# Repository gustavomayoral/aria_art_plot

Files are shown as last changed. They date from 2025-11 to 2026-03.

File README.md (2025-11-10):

# Aria Art Plotter





**Professional large-format CNC drawing machine for artists and creators**

This is the Aria Art Plotter, a pen plotter made for artist.

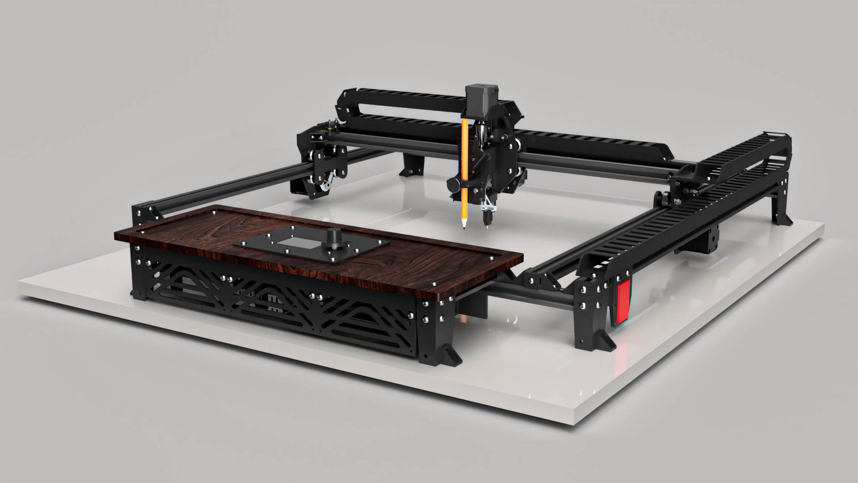
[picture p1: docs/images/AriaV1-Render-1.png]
Aria Art Plotter


---

## ✨ Key Features

- **Large Drawing Area**: 500mm × 500mm (20" × 20") usable area, expandable
- **Multi-Tool Support**: Pens, pencils, brushes, stamps, and more
- **Artist-Friendly**: Simplified interface designed for creators, not engineers
- **Whisper Quiet**: Silent TMC2209 stepper drivers
- **Smart Compensation**: Dual mesh system for beds and canvases
- **Remote Control**: WiFi/Ethernet connectivity with web interface
- **Open Source**: Complete build documentation, all files included

---

## 📋 What's Included in This Repository

This is a **complete open source package** to build your own Aria Art Plotter:

- **📘 170-Page Assembly Guide** - Complete safety instructions, BOM, visual IKEA-style assembly
- **🎥 15 Video Tutorials** - Step-by-step build process ([YouTube Channel](https://www.youtube.com/@aria_art_plot))
- **🔧 All Design Files**:
  - STL files for 3D printing
  - DXF files for CNC/laser cutting
  - 1 Arduino sketch
  - 3 Klipper configuration files with custom macros
  - 1 Python support file
- **📦 Complete Bill of Materials** - Every component with sources and alternatives

---

## 🎯 Who Is This For?

- **Artists** wanting to create large-format physical artwork from digital designs
- **Makers** interested in precision CNC systems and creative robotics
- **Educators** teaching about digital fabrication and art technology
- **Hobbyists** who enjoy building capable, professional-grade tools

---

## 🚀 Quick Start

### Prerequisites

- Basic mechanical assembly skills
- 3D printer access (for printed parts)
- Basic electronics knowledge (soldering, crimping)
- Budget: Cost of Materials. Check BOM on Amazon here: 

### Build Process Overview

1. **Review Documentation**: Read the [Assembly Guide](docs/AriaArtPlotterAssemblyManual_V1.pdf)
3. **Print Parts**: Download [STL files](hardware/stl/) and print components as per manual instruction
4. **Optional Cut Parts**: Process [DXF files](hardware/dxf/) for frame parts
5. **Assemble**: Follow video tutorials and assembly guide
6. **Install Firmware**: Configure [Klipper](firmware/klipper/) on the CB1
7. **Calibrate**: Run test patterns and mesh compensation
8. **Create**: Start drawing!

**Estimated Build Time**: 20-30 hours total

---

## 🔧 Technical Specifications

### Drawing Capabilities
- **Drawing Area**: 500mm × 500mm (20" × 20"), expandable
- **Z-Axis Travel**: 37mm adjustable to 42mm

### Mechanical System
- **Frame**: 2020 aluminum extrusion (20×20, Expandable to 40×40)
- **Motion**: Dual Y-axis motors, MGN12 linear rails, T8 lead screw
- **Wheels**: 24mm V-wheels for smooth operation

### Electronics
- **Controller**: BIGTREETECH Manta M5P V1.0 (32-bit ARM)
- **Compute**: BIGTREETECH CB1 V2.2
- **Drivers**: TMC2209 V1.3 (4×) - Silent operation
- **Motors**: NEMA 17 high-precision steppers
- **Firmware**: Klipper with custom macros
- **Display**: Mini12864 V2.0 LCD & .91 OLED Display
- **Probe**: BIQU MicroProbe V2 auto-leveling

### Advanced Features
- Tool support (pens, pencils, brushes, stamps, etc)
- Spring-loaded pressure control
- Dual mesh compensation (bed + canvas)
- Built-in test patterns
- WiFi/Ethernet connectivity
- Web interface (Mainsail/Fluidd)

[Full specifications →](docs/specifications.md)

---

## 🎥 Video Tutorials

Complete video build series available on our [YouTube Channel](https://www.youtube.com/@aria_art_plot):

---

## 🤝 Community & Support

- **Website**: [aria-art.com](https://aria-art.com/)
- **YouTube**: [@aria_art_plot](https://www.youtube.com/@aria_art_plot)
- **X/Twitter**: [@aria_art_plot](https://twitter.com/aria_art_plot)
- **Instagram**: [@aria_art_plot](https://instagram.com/aria_art_plot)
- **Threads**: [@aria_art_plot](https://threads.net/@aria_art_plot)
- **Printables**: [Aria Art Plotter](https://www.printables.com/@aria_art_3610199)
- **GitHub Discussions**: Share builds, ask questions, get help

### Contributing

We welcome contributions! Whether it's:
- **Bug fixes** and improvements
- **Documentation** enhancements
- **New features** and modifications
- **User builds** and artwork showcase

Please read [CONTRIBUTING.md](community/CONTRIBUTING.md) for guidelines.

---

## 📜 License

This project uses dual licensing:

- **Hardware** (STL, DXF, CAD): [CERN-OHL-S-2.0](LICENSE-HARDWARE.txt) - Strong reciprocal open hardware license
- **Documentation** (Assembly guide, docs): [CC BY-SA 4.0](LICENSE-DOCS.txt) - Creative Commons Attribution-ShareAlike

**Software/Firmware** (Arduino, Klipper configs, Python): GPL-3.0 (standard for Klipper derivatives)

### What This Means

✅ **You CAN**:
- Build and sell plotters using these designs
- Modify and improve the design
- Use commercially
- Share and distribute

📋 **You MUST**:
- Share your modifications under the same license
- Credit the original project
- Document your changes
- Keep the same license terms

---

## 🙏 Acknowledgments

- Klipper firmware team for exceptional CNC control software
- BIGTREETECH for accessible, powerful electronics
- The open source 3D printing and CNC community
- All the beta builders and testers who helped refine this design

---

## 📞 Support This Project

If the Aria Art Plotter helps you create amazing work:
- ⭐ **Star this repository**
- 📢 **Share your builds** on social media (tag @aria_art_plot)
- 🎨 **Show your artwork** in Discussions
- 🐛 **Report issues** to help improve the design
- 💡 **Contribute** improvements and modifications

---

**Ready to build?** Start with the [Assembly Guide](docs/assembly-guide.pdf) or watch the [Introduction Video](https://www.youtube.com/@aria_art_plot)!

*Making professional large-format art creation accessible to everyone.*

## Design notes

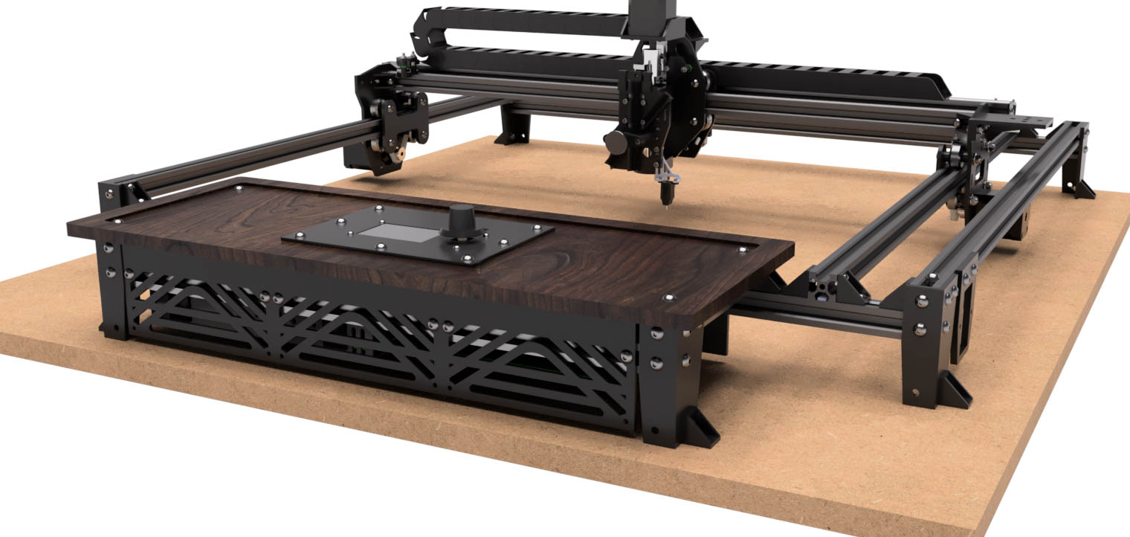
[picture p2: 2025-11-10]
docs/images/AriaV1-Render-4.png

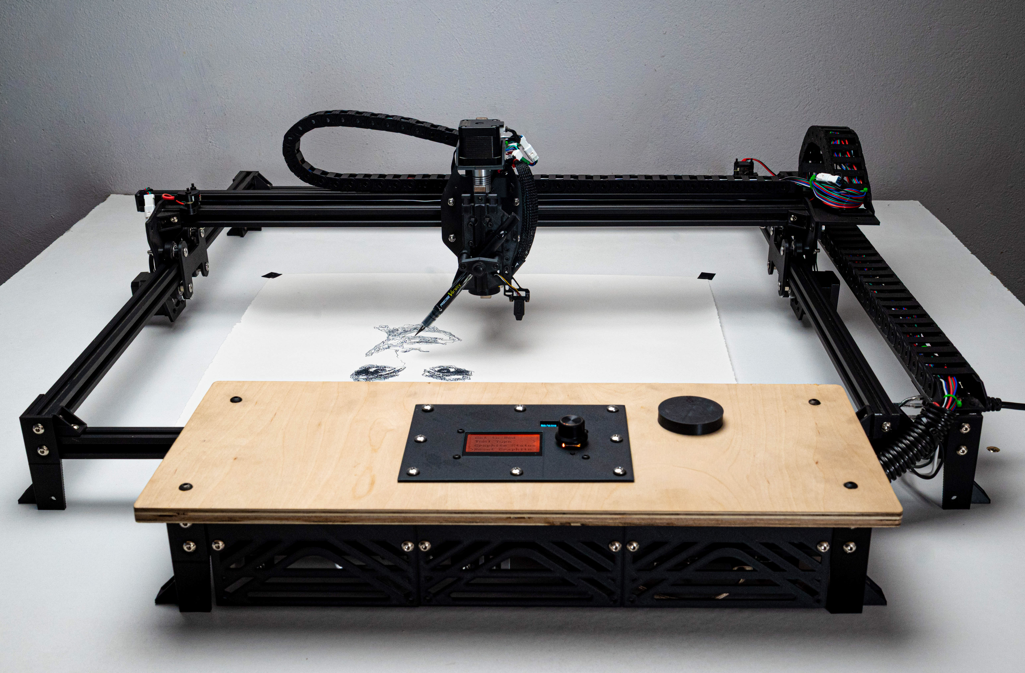
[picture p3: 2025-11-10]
docs/images/AriaV1-2.jpg

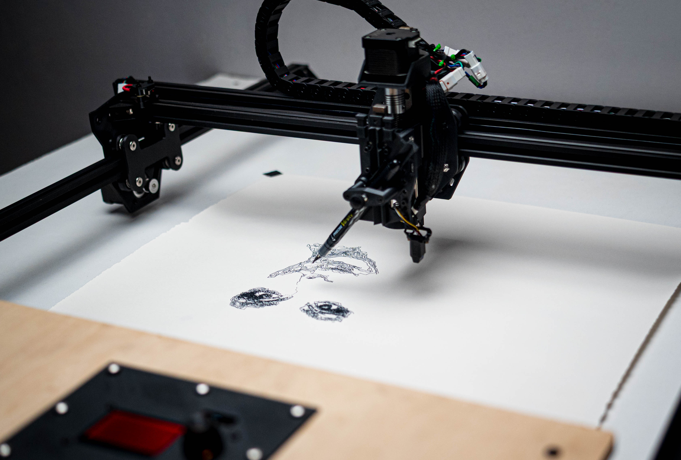
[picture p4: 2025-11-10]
docs/images/AriaV1-9.jpg

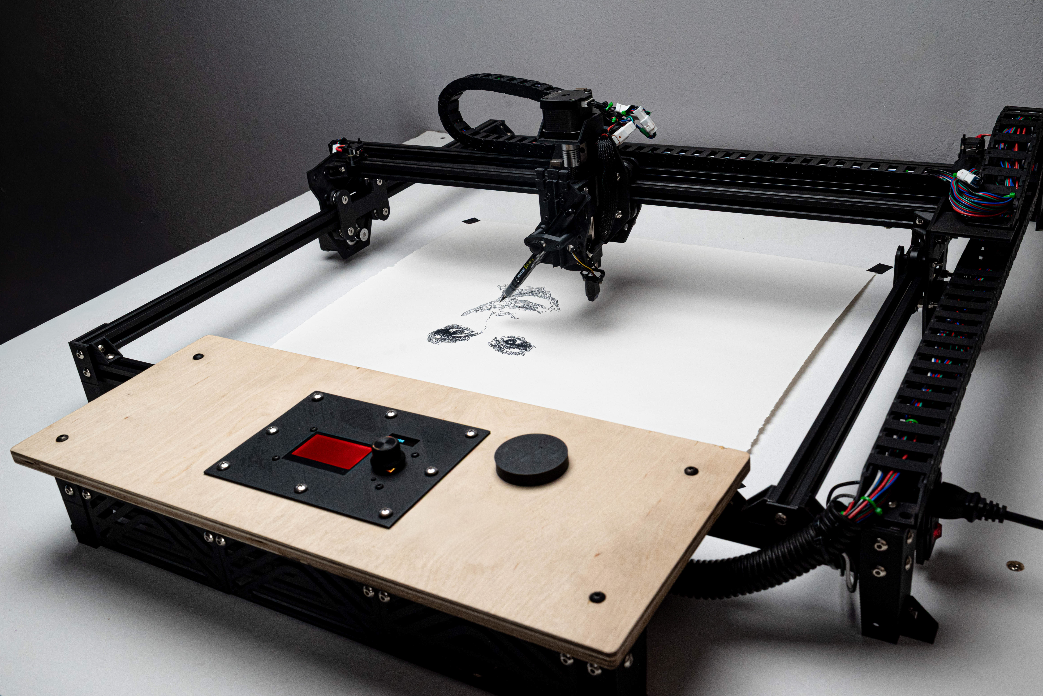
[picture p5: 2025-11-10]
docs/images/AriaV1-1.jpg

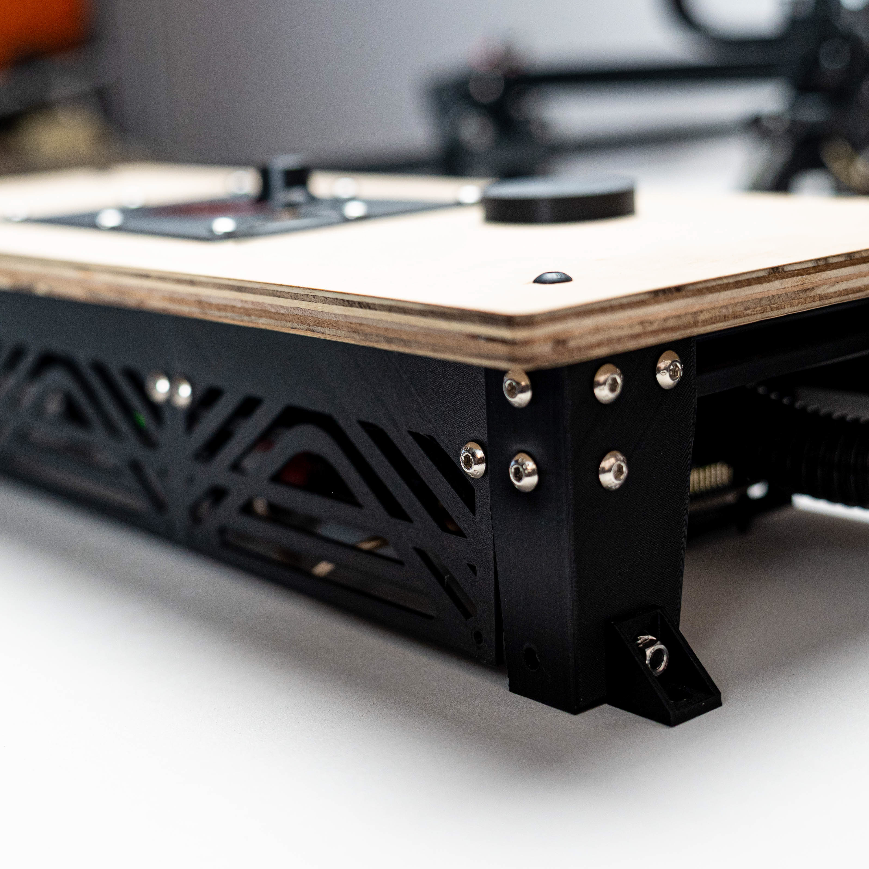
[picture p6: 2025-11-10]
docs/images/AriaV1-5.jpg

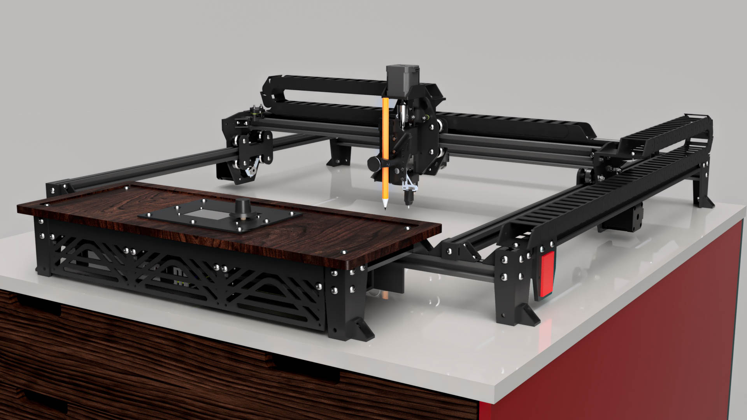
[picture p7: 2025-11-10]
docs/images/AriaV1-Render-3.png

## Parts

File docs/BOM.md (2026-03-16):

# Aria Art Plotter - Bill of Materials

**Build Cost:** ~$450-550 USD  

> 💡 Amazon links are affiliated and support Version 2.0 development at no extra cost to you.  
> Alternative sourcing options (AliExpress, local suppliers) 

---

## Electronics

| Qty | Component | Specification | Notes | Link |
|-----|---|---|---|---|
| 1 | Main Board | BIGTREETECH Manta M5P V1.0 | - | [Amazon](https://amzn.to/49a1JgA) |
| 1 | MCU | BIGTREETECH CB1 V2.2 | Included in M5P kit | [Amazon](https://amzn.to/49a1JgA) |
| 1 | Heatsink | BIGTREETECH CB1 Heatsink | Required for CB1 | [Amazon](https://amzn.to/3Lx8sXW) |
| 4 | Stepper Drivers | BIGTREETECH TMC2209 V1.3 | For X, 2Y, Z axes | [Amazon](https://amzn.to/4ovlbsY) |
| 4 | Stepper Motors | NEMA 17 | 1.8° step angle | [Amazon](https://amzn.to/4nLkdHN) |
| 1 | Display | BIGTREETECH Mini12864 V2.0 | LCD Graphic Smart Display | [Amazon](https://amzn.to/49G2H48) |
| 1 | OLED Display | 0.91" OLED I2C Display | Pre-soldered preferred | [Amazon](https://amzn.to/4orxmGV) |
| 1 | Microcontroller | Seeeduino Xiao | Non-ESP version | [Amazon](https://amzn.to/4qP1rlw) |
| 1 | Power Supply | Mean Well LRS-350-24 | 24V 350W | [Amazon](https://amzn.to/4hLWdTo) |
| 1 | Limit Switch | REIFENG Limit Switch | Model B07PCN6T6F | [Amazon](https://amzn.to/4os5JNY) |
| 1 | Power Socket | AC-01A 10A 250V | Must include fuse or add 10A fuse | [Amazon](https://amzn.to/4oWWxB7) |
| 1 | Auto Bed Leveling | BIQU MicroProbe V2.0 Kit | Includes B1/H2 V2S bracket | [Amazon](https://amzn.to/4nLnPJI) |
| 3 | JST Connectors 4P(F) | JST-XH Connector | For steppers (usually included with M5P) | [Amazon](https://amzn.to/49a1JgA) |
| 6 | JST Connectors 3P(F) | JST-XH Connector | For limit switches (usually included with M5P) | [Amazon](https://amzn.to/49a1JgA) |

### Wiring & Connectors

| Qty | Component | Specification | Notes | Link |
|-----|---|---|---|---|
| 30 ft | Stepper Cable | 22 AWG, 4-conductor | For stepper motor cables | [Amazon](https://amzn.to/47u0bwz) |
| 21 ft | Switch Cable | 22 AWG, 2-conductor | For limit switches | [Amazon](https://amzn.to/4ooMlS9) |
| 9 ft | Probe Cable | 22 AWG, 5-conductor | For probe | [Amazon](https://amzn.to/4oxtx3c) |
| 2 pc | DC Wiring | 18 AWG, ~5 ft each | Red and Black (consult Section 6) | [Amazon](https://amzn.to/43mbBzX) |
| 6 ft | AC Wiring | 14 AWG | Optional (consult Section 6) | [Amazon](https://amzn.to/3LlG774) |
| 1 | JST Connector 6P | JWF-VSLE Series | For probe on pen side | [Amazon](https://amzn.to/3LOpSiQ) |
| 4 | JST Connector 4P | JWF-VSLE Series | For NEMA motors on plotter side | [Amazon](https://amzn.to/3Lrh6Y5) |
| 100 | Crimping Terminals | AMP-TE | Usually included with M5P | [Amazon](https://amzn.to/492HrW9) |
| 2 | JST-XH 2P(M) | JST-XH Connector | Power/data for Xiao & OLED | Included with M5P |
| 1 | JST-XH 4P(M) | JST-XH Connector | Power/data for Xiao & OLED | Included with M5P |
| 1 | Dupont Cable | 4-conductor F-F, ~8 inch | - | [Amazon](https://amzn.to/4nMufZf) |
| 1 | USB Cable | USB-C to USB-A, 1 ft | Data capable (not power-only) | [Amazon](https://amzn.to/497YrKL) |

---

## Hardware & Motion

| Qty | Component | Specification | Notes | Link |
|-----|---|---|---|---|
| 6m | Aluminum Extrusion | 2020 V-SLOT Profile | 20 ft - buy extra for mistakes | [Amazon](https://amzn.to/3Lzcj6N) |
| 12 | V-Slot Wheels | POM Wheels, 5mm bore | - | [Amazon](https://amzn.to/43UkyAL) |
| 12 | Eccentric Spacers | PCS Eccentric Spacers | - | [Amazon](https://amzn.to/43UkyAL) |
| 1 | Drag Chain Small | R18 10x15, 39.3" | For 20x20 plotter | [Amazon](https://amzn.to/43WwS3m) |
| 1 | Drag Chain Large | R28 15x30, 39.4" | For 20x20 plotter | [Amazon](https://amzn.to/43OVmLY) |
| 10 ft | GT2 Timing Belt | 2mm pitch, 6mm wide | - | [Amazon](https://amzn.to/3Xgb27d) |
| 3 | GT2 Pulley | 20 teeth, 5mm bore, 6mm width | - | [Amazon](https://amzn.to/4qNTSvf) |
| 1 | Ball Bearing | 8mm×19mm×6mm, flanged | - | [Amazon](https://amzn.to/4qKgzAN) |
| 1 | Lead Screw | T8, 150mm length | Includes brass nut | [Amazon](https://amzn.to/4oYJ3VA) |
| 1 | T8 Brass Nut | - | Sold with lead screw | [Amazon](https://amzn.to/4oYJ3VA) |
| 1 | Flexible Coupling | 5mm to 8mm shaft | - | [Amazon](https://amzn.to/47EYGff) |
| 1 | Linear Rail | MGN12, 200mm | With MGN12H carriage | [Amazon](https://a.co/d/0fwBGblU) |
| 1 | Linear Rail | MGN12, 100mm | With MGN12H carriage (or cut 200mm) | [Amazon](https://a.co/d/08qK8v18) |
| 1 | Compression Spring | 0.7×7×15mm, 8 coils | Stainless steel | [Amazon](https://amzn.to/4orAt1z) |
| 1 | Thumb Screw | M6×25mm knob | - | [Amazon](https://amzn.to/47vAuMb) |
| 1 | Thumb Screw | M4×25mm knob | - | [Amazon](https://amzn.to/47vAuMb) |
| 1 | Threaded Insert | M6×8×8mm brass | - | [Amazon](https://amzn.to/49H7JNU) |
| 1 | Threaded Insert | M4×6×6mm brass | - | [Amazon](https://amzn.to/49H7JNU) |
| 1 | Rubber Band | - | Optional if not using spring mechanism | Local supply |

---

## Fasteners

### M5 Fasteners

| Qty | Component | Specification | Notes | Link |
|-----|---|---|---|---|
| 22 | Self-Tapping Screws | M5×10 or M5×8 (or #10-24) | For 2020 extrusion face plate | [Amazon](https://amzn.to/3JCL1vS) |
| 14 | Button Head Screws | M5×12 | - | [Amazon](https://amzn.to/3JCL1vS) |
| 6 | Button Head Screws | M5×16 | - | [Amazon](https://amzn.to/3JCL1vS) |
| 85 | Button Head Screws | M5×8 | - | [Amazon](https://amzn.to/47L2sT4) |
| 14 | Button Head Screws | M5×40 | - | [Amazon](https://amzn.to/4qInYjP) |
| 2 | Button Head Screws | M5×30 | - | [Amazon](https://amzn.to/4qTFFxa) |
| 19 | Nuts | M5 | - | [Amazon](https://amzn.to/4nFjJCV) |
| 14 | Locking Nuts | M5 Nylon Insert | - | [Amazon](https://amzn.to/4hQLt6f) |
| 13 | Locking Washers | M5 Star | - | [Amazon](https://amzn.to/47MtgSK) |
| 81 | Sliding Nuts | M5 for 2020 V-Slot | - | [Amazon](https://amzn.to/4nK0OqD) |
| 6 | T-Nuts | M5 Flat Sliding for T-Slot | - | [Amazon](https://amzn.to/4nFSHez) |
| 8 | Sheet Metal Screws | M5 or #10, Pan Head | For screen (length depends on panel) | Local supply |

### M3 & M4 Fasteners

| Qty | Component | Specification | Notes | Link |
|-----|---|---|---|---|
| 4 | Button Head Screws | M4×8 | - | [Amazon](https://amzn.to/43iiQJe) |
| 4 | Sheet Metal Screws | M3, Pan Head | For card reader (length depends on panel) | Local supply |
| 4 | Hex Head Cap Screws | M3×8 | - | [Amazon](https://amzn.to/4qTFFxa) |
| 8 | Hex Head Cap Screws | M3×12 | - | [Amazon](https://amzn.to/4qTFFxa) |
| 22 | Button Head Screws | M3×8 | - | [Amazon](https://amzn.to/4qTFFxa) |
| 17 | Button Head Screws | M3×12 | - | [Amazon](https://amzn.to/4qTFFxa) |
| 2 | Button Head Screws | M3×25 | - | [Amazon](https://amzn.to/4qTFFxa) |
| 29 | Nuts | M3 | - | [Amazon](https://amzn.to/4qTFFxa) |
| 7 | Flat Washers | M3 | - | [Amazon](https://amzn.to/4qTFFxa) |
| 13 | Locking Washers | M3 | - | [Amazon](https://amzn.to/4qTFFxa) |

---

## Additional Materials

| Qty | Component | Specification | Notes | Link |
|-----|---|---|---|---|
| As needed | Zip Ties | Small & Medium | For cable management | Local supply |
| 6 in | Expanded Sleeving | ½ inch | Optional for pen probe wiring | [Amazon](https://amzn.to/47R38X1) |
| 1 ft | Wire Loom Tubing | 1 inch split | - | [Amazon](https://amzn.to/47Msl4Y) |
| As needed | Ferrule Terminals | - | For clean wire ends | [Amazon](https://amzn.to/3JrZyum) |
| 6m | Slot Cover | Aluminum extrusion | - | [Amazon](https://amzn.to/47vTqdK) |
| 1 | AC Power Cord | 3-prong, 10A 125V | Standard black cable | [Amazon](https://amzn.to/47R2xEL) |
| As needed | Heat Shrink Tubing | Various sizes | For wire insulation | [Amazon](https://amzn.to/480zWxU) |

---

## 3D Printed Parts

All STL files available in the `/STL/` directory on GitHub.

**Filament Required:** ~2.5kg  
**Recommended Material:** PETG or ABS  
**Print Settings:** 0.2mm layer height, 20-30% infill

See the assembly guide for detailed print orientations and support requirements.

---

## Alternative Sourcing

For builders outside the US or seeking lower costs:
- **AliExpress:** Most electronics available at 30-50% savings
- **Local Hardware Stores:** Generic fasteners, wire, zip ties
- **Official Stores:** BIGTREETECH, BIQU direct for electronics

---

## Cost Breakdown

| Category | Est. Cost |
|---|---|
| Electronics | $200-250 |
| Motion Hardware | $120-150 |
| Fasteners | $40-60 |
| Extrusion & Frame | $60-80 |
| Misc Materials | $30-50 |
| **Total** | **$450-550** |

*Prices approximate as of November 2025. Check links for current pricing.*

---

## Notes

- **Bulk Savings:** Consider hardware assortment kits for M3/M5 fasteners
- **Tools Required:** Allen keys, crimping tool (included with some kits), screwdrivers, wire strippers
- **Cut List:** Detailed aluminum extrusion cut list in assembly guide Section 3

---

**Questions?** Open an issue on GitHub or join the discussion!  
**Support the Project:** [Buy me a coffee ☕](https://ko-fi.com/ariaartplot)

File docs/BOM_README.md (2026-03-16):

# Bill of Materials (BOM)

Complete parts list for building your own Aria Art Plotter.

## 📋 Available Formats

- **[BOM.md](BOM.md)** - Main version, human-readable with organized categories
- **[BOM.xlsx](BOM.xlsx)** - Excel spreadsheet with clickable links and pricing
- **[BOM.csv](BOM.csv)** - Machine-readable format for importing

## 💰 Cost Summary

| Category | Estimated Cost |
|---|---|
| Electronics | $200-250 |
| Motion Hardware | $120-150 |
| Fasteners | $40-60 |
| Extrusion & Frame | $60-80 |
| Materials & Misc | $30-50 |
| **Total** | **$450-550** |

*Prices as of November 2025, subject to market variation*

## 🛠️ Build Requirements

- **Build Time:** 20-40 hours
- **Skill Level:** Intermediate
- **3D Printing:** ~2.5kg filament (PETG or ABS recommended)
- **Tools Required:** 
  - Allen key set (metric)
  - Crimping tool (often included with JST kits)
  - Wire strippers
  - Screwdrivers
  - Measuring tape

## 📦 Sourcing Options

### Option 1: Amazon (USA)
- Fast shipping (Prime eligible items)
- Easy returns
- Links in BOM are affiliated (supports v2.0 development)
- No extra cost to you

### Option 2: AliExpress (Worldwide)
- 30-50% cost savings on electronics
- Longer shipping times (2-6 weeks)
- Bulk component availability
- Great for international builders

### Option 3: Direct from Manufacturers
- **BIGTREETECH:** Official store for Manta, CB1, TMC2209
- **BIQU:** Official store for MicroProbe
- **Mean Well:** Official distributors for power supplies

### Option 4: Local Hardware Stores
- Generic fasteners (M3, M5 bolts/nuts)
- Wire and cables
- Zip ties and cable management
- Heat shrink tubing

## 🔍 Component Notes

### Critical Components (Don't Substitute)
- BIGTREETECH Manta M5P (firmware optimized for this board)
- TMC2209 stepper drivers (silent operation, UART mode)
- MGN12 linear rails (precision critical)
- Mean Well LRS-350-24 PSU (reliable 24V power)

### Flexible Components (Substitution OK)
- Generic fasteners (M3/M5 hardware)
- Wire/cables (as long as gauge matches)
- Drag chains (similar dimensions work)
- Zip ties and cable management

### Optional Components
- Rubber band (if not using spring mechanism)
- Expanded sleeving (aesthetic wire management)
- AC wiring (if not using included power cord)

## 📐 Aluminum Extrusion Cut List

For 500mm × 500mm (20" × 20") plotter (Check the Manual for any updates):

| Quantity | Length | Purpose |
|---|---|---|
| 2 | 660mm | X-axis frame sides |
| 2 | 620mm | Y-axis frame sides |
| 2 | 660mm | Z-axis verticals |
| 2 | 540mm | Gantry rails |
| 1 | 620mm | Pen assembly rail |

**Total required:** 6 meters (20 feet)  
**Recommendation:** Order 7-8 meters for practice cuts and mistakes

## 🧵 3D Printed Parts

All STL files available in [`/STL/`](../STL/) directory.

**Filament Requirements:**
- Total weight: ~2.5kg
- Recommended: PETG (durability) or ABS (rigidity)
- Alternative: PLA+ (budget option, less durable)

**Print Settings:**
- Layer height: 0.2mm
- Infill: 20-30%
- Supports: Required for some parts (see assembly guide)
- Bed adhesion: Recommended for ABS

See [Assembly Guide](../docs/AriaArtPlotterAssemblyManual.pdf) for part-by-part print orientations.

## ⚡ Wiring Requirements

### Cable Lengths (minimum)
- Stepper motors: 30 ft (22 AWG 4-conductor)
- Limit switches: 21 ft (22 AWG 2-conductor)
- Probe: 9 ft (22 AWG 5-conductor)
- DC power: 10 ft (18 AWG red/black)
- AC power (optional): 6 ft (14 AWG)

**Tip:** Buy extra wire (Amazon links includes extras)- it's cheaper than running short mid-build!

## 🔧 Assembly Sections Reference

The BOM is organized to match the assembly guide sections:

1. **Electronics** Components and Wiring 
2. **Hardware:** Motion System and Frame (Rails, belts, wheels)
3. **Fasteners** Complete list of what you need
4. **Additional Materials:** Wiring Management etc.

## 🌍 International Builders

### Voltage Considerations
- Power supply is universal input (110-240V)
- AC power cord may need regional adapter
- Check local electrical codes

### Metric vs Imperial
- All fasteners are metric (M3, M4, M5)
- Extrusions are 2020 profile (20mm × 20mm)
- Some US suppliers list in inches (conversions provided)

## 💡 Money-Saving Tips

1. **Buy hardware kits suggested** instead of individual fasteners (Amazon links)
2. **Source extrusions locally** (cheaper than shipping)
3. **Print your own drag chains** (STLs available online)
4. **Use AliExpress for electronics** if timeline permits
5. **Buy generic crimps** instead of branded (same quality)
6. **Check for BIQU/BTT sales** (frequent promotions)
7. **Join group buys** in maker communities

## 🆘 BOM Support

### Something Missing?
Open an issue: [GitHub Issues](https://github.com/gustavomayoral/aria_art_plot/issues)

### Found a Better Alternative?
Submit a pull request with:
- Component name
- Alternative part number
- Why it's better/cheaper
- Compatibility notes

### Questions About Sourcing?
- Check the [Discussions](https://github.com/gustavomayoral/aria_art_plot/discussions)
- Join community Discord (we are woring on it)
- Tag your question with `#bom` or `#sourcing`

## 🤝 Contributing

Help improve this BOM:
- Add alternative suppliers for your region
- Update pricing information
- Report broken/changed links
- Suggest better component alternatives
- Translate for international builders

See [CONTRIBUTING.md](../CONTRIBUTING.md) for guidelines.

## 📜 Affiliate Disclosure

Amazon links in this BOM are affiliated. This means:
- ✅ You pay the same price
- ✅ I receive a small commission (~3-5%)
- ✅ Funds support Version 2.0 development
- ✅ All design files remain 100% free

**You are never required to use affiliate links.** Full component specifications are provided so you can source anywhere.

## ☕ Support This Project

If this BOM helped you save time or money:
- [Buy me a coffee](https://ko-fi.com/ariaartplot)
- Star this repository
- Share with the maker community
- Contribute improvements

---

**Last Updated:** November 2025  
**BOM Version:** 1.0  
**Compatible with:** Aria Art Plotter v1.0

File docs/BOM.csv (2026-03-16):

Category | Qty | Component | Specification | Notes | Amazon_Link | AliExpress_Alternative
Electronics | 1 | Main Board | BIGTREETECH Manta M5P V1.0 |  | https://amzn.to/49a1JgA | Yes
Electronics | 1 | MCU | BIGTREETECH CB1 V2.2 | Included in M5P kit | https://amzn.to/49a1JgA | Yes
Electronics | 1 | Heatsink | BIGTREETECH CB1 Heatsink | Required for CB1 | https://amzn.to/3Lx8sXW | Yes
Electronics | 4 | Stepper Drivers | BIGTREETECH TMC2209 V1.3 | For X, 2Y, Z axes | https://amzn.to/4ovlbsY | Yes
Electronics | 4 | Stepper Motors | NEMA 17 | 1.8° step angle | https://amzn.to/4nLkdHN | Yes
Electronics | 1 | Display | BIGTREETECH Mini12864 V2.0 | LCD Graphic Smart Display | https://amzn.to/49G2H48 | Yes
Electronics | 1 | OLED Display | 0.91" OLED I2C Display | Pre-soldered preferred | https://amzn.to/4orxmGV | Yes
Electronics | 1 | Microcontroller | Seeeduino Xiao | Non-ESP version | https://amzn.to/4qP1rlw | Yes
Electronics | 1 | Power Supply | Mean Well LRS-350-24 | 24V 350W | https://amzn.to/4hLWdTo | Yes
Electronics | 1 | Limit Switch | REIFENG Limit Switch | Model B07PCN6T6F | https://amzn.to/4os5JNY | Yes
Electronics | 1 | Power Socket | AC-01A 10A 250V | Must include fuse or add 10A fuse | https://amzn.to/4oWWxB7 | Yes
Electronics | 1 | Auto Bed Leveling | BIQU MicroProbe V2.0 Kit | Includes B1/H2 V2S bracket | https://amzn.to/4nLnPJI | Yes
Electronics | 3 | JST Connectors 4P(F) | JST-XH Connector | For steppers (usually included with M5P) | https://amzn.to/49a1JgA | Yes
Electronics | 6 | JST Connectors 3P(F) | JST-XH Connector | For limit switches (usually included with M5P) | https://amzn.to/49a1JgA | Yes
Wiring | 30 ft | Stepper Cable | 22 AWG 4-conductor | For stepper motor cables | https://amzn.to/47u0bwz | Yes
Wiring | 21 ft | Switch Cable | 22 AWG 2-conductor | For limit switches | https://amzn.to/4ooMlS9 | Yes
Wiring | 9 ft | Probe Cable | 22 AWG 5-conductor | For probe | https://amzn.to/4oxtx3c | Yes
Wiring | 2 pc | DC Wiring | 18 AWG ~5 ft each | Red and Black (consult Section 6) | https://amzn.to/43mbBzX | Yes
Wiring | 6 ft | AC Wiring | 14 AWG | Optional (consult Section 6) | https://amzn.to/3LlG774 | No
Wiring | 1 | JST Connector 6P | JWF-VSLE Series | For probe on pen side | https://amzn.to/3LOpSiQ | Yes
Wiring | 4 | JST Connector 4P | JWF-VSLE Series | For NEMA motors on plotter side | https://amzn.to/3Lrh6Y5 | Yes
Wiring | 100 | Crimping Terminals | AMP-TE | Usually included with M5P | https://amzn.to/492HrW9 | Yes
Wiring | 2 | JST-XH 2P(M) | JST-XH Connector | Power/data for Xiao & OLED | Included with M5P | Yes
Wiring | 1 | JST-XH 4P(M) | JST-XH Connector | Power/data for Xiao & OLED | Included with M5P | Yes
Wiring | 1 | Dupont Cable | 4-conductor F-F ~8 inch |  | https://amzn.to/4nMufZf | Yes
Wiring | 1 | USB Cable | USB-C to USB-A 1 ft | Data capable (not power-only) | https://amzn.to/497YrKL | Yes
Hardware | 6m | Aluminum Extrusion | 2020 V-SLOT Profile | 20 ft - buy extra for mistakes | https://amzn.to/3Lzcj6N | Yes
Hardware | 12 | V-Slot Wheels | POM Wheels 5mm bore |  | https://amzn.to/43UkyAL | Yes
Hardware | 12 | Eccentric Spacers | PCS Eccentric Spacers |  | https://amzn.to/43UkyAL | Yes
Hardware | 1 | Drag Chain Small | R18 10x15 39.3" | For 20x20 plotter | https://amzn.to/43WwS3m | Yes
Hardware | 1 | Drag Chain Large | R28 15x30 39.4" | For 20x20 plotter | https://amzn.to/43OVmLY | Yes
Hardware | 10 ft | GT2 Timing Belt | 2mm pitch 6mm wide |  | https://amzn.to/3Xgb27d | Yes
Hardware | 3 | GT2 Pulley | 20 teeth 5mm bore 6mm width |  | https://amzn.to/4qNTSvf | Yes
Hardware | 1 | Ball Bearing | 8mm×19mm×6mm flanged |  | https://amzn.to/4qKgzAN | Yes
Hardware | 1 | Lead Screw | T8 150mm length | Includes brass nut | https://amzn.to/4oYJ3VA | Yes
Hardware | 1 | T8 Brass Nut |  | Sold with lead screw | https://amzn.to/4oYJ3VA | Yes
Hardware | 1 | Flexible Coupling | 5mm to 8mm shaft |  | https://amzn.to/47EYGff | Yes
Hardware | 1 | Linear Rail | MGN12 200mm | With MGN12H carriage | https://a.co/d/0fwBGblU | Yes
Hardware | 1 | Linear Rail | MGN12 100mm | With MGN12H carriage (or cut 200mm) | https://a.co/d/08qK8v18 | Yes
Hardware | 1 | Compression Spring | 0.7×7×15mm 8 coils | Stainless steel | https://amzn.to/4orAt1z | Yes
Hardware | 1 | Thumb Screw | M6×25mm knob |  | https://amzn.to/47vAuMb | Yes
Hardware | 1 | Thumb Screw | M4×25mm knob |  | https://amzn.to/47vAuMb | Yes
Hardware | 1 | Threaded Insert | M6×8×8mm brass |  | https://amzn.to/49H7JNU | Yes
Hardware | 1 | Threaded Insert | M4×6×6mm brass |  | https://amzn.to/49H7JNU | Yes
Hardware | 1 | Rubber Band |  | Optional if not using spring mechanism |  | No
Fasteners-M5 | 22 | Self-Tapping Screws | M5×10 or M5×8 (or #10-24) | For 2020 extrusion face plate | https://amzn.to/3JCL1vS | Yes
Fasteners-M5 | 14 | Button Head Screws | M5×12 |  | https://amzn.to/3JCL1vS | Yes
Fasteners-M5 | 6 | Button Head Screws | M5×16 |  | https://amzn.to/3JCL1vS | Yes
Fasteners-M5 | 85 | Button Head Screws | M5×8 |  | https://amzn.to/47L2sT4 | Yes
Fasteners-M5 | 14 | Button Head Screws | M5×40 |  | https://amzn.to/4qInYjP | Yes
Fasteners-M5 | 2 | Button Head Screws | M5×30 |  | https://amzn.to/4qTFFxa | Yes
Fasteners-M5 | 19 | Nuts | M5 |  | https://amzn.to/4nFjJCV | Yes
Fasteners-M5 | 14 | Locking Nuts | M5 Nylon Insert |  | https://amzn.to/4hQLt6f | Yes
Fasteners-M5 | 13 | Locking Washers | M5 Star |  | https://amzn.to/47MtgSK | Yes
Fasteners-M5 | 81 | Sliding Nuts | M5 for 2020 V-Slot |  | https://amzn.to/4nK0OqD | Yes
Fasteners-M5 | 6 | T-Nuts | M5 Flat Sliding for T-Slot |  | https://amzn.to/4nFSHez | Yes
Fasteners-M5 | 8 | Sheet Metal Screws | M5 or #10 Pan Head | For screen (length depends on panel) |  | No
Fasteners-M3/M4 | 4 | Button Head Screws | M4×8 |  | https://amzn.to/43iiQJe | Yes
Fasteners-M3/M4 | 4 | Sheet Metal Screws | M3 Pan Head | For card reader (length depends on panel) |  | No
Fasteners-M3/M4 | 4 | Hex Head Cap Screws | M3×8 |  | https://amzn.to/4qTFFxa | Yes
Fasteners-M3/M4 | 8 | Hex Head Cap Screws | M3×12 |  | https://amzn.to/4qTFFxa | Yes
Fasteners-M3/M4 | 22 | Button Head Screws | M3×8 |  | https://amzn.to/4qTFFxa | Yes
Fasteners-M3/M4 | 17 | Button Head Screws | M3×12 |  | https://amzn.to/4qTFFxa | Yes
Fasteners-M3/M4 | 2 | Button Head Screws | M3×25 |  | https://amzn.to/4qTFFxa | Yes
Fasteners-M3/M4 | 29 | Nuts | M3 |  | https://amzn.to/4qTFFxa | Yes
Fasteners-M3/M4 | 7 | Flat Washers | M3 |  | https://amzn.to/4qTFFxa | Yes
Fasteners-M3/M4 | 13 | Locking Washers | M3 |  | https://amzn.to/4qTFFxa | Yes
Materials | As needed | Zip Ties | Small & Medium | For cable management |  | No
Materials | 6 in | Expanded Sleeving | ½ inch | Optional for pen probe wiring | https://amzn.to/47R38X1 | Yes
Materials | 1 ft | Wire Loom Tubing | 1 inch split |  | https://amzn.to/47Msl4Y | Yes
Materials | As needed | Ferrule Terminals |  | For clean wire ends | https://amzn.to/3JrZyum | Yes
Materials | 6m | Slot Cover | Aluminum extrusion |  | https://amzn.to/47vTqdK | Yes
Materials | 1 | AC Power Cord | 3-prong 10A 125V | Standard black cable | https://amzn.to/47R2xEL | No
Materials | As needed | Heat Shrink Tubing | Various sizes | For wire insulation | https://amzn.to/480zWxU | Yes
3D_Printed | ~2.5kg | Filament | PETG or ABS recommended | See /STL/ directory for files |  | N/A

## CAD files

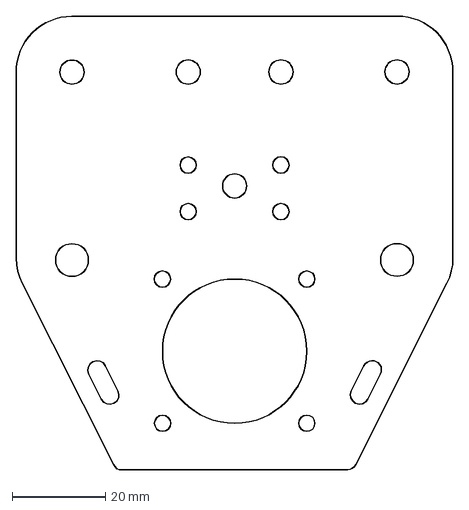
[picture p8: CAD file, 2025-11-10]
hardware/dxf/0008_XAxisBackPlateSketch.dxf
93.9 x 97.5 mm

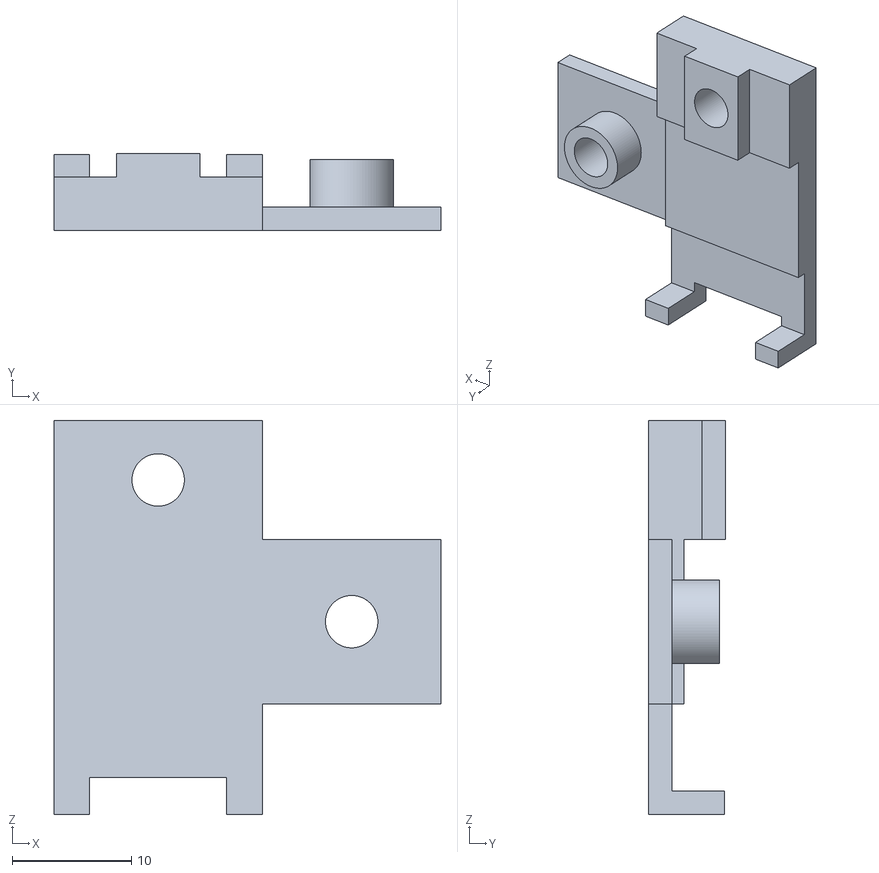
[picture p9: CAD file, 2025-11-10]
hardware/stl/0033_XiaoBracketBottom.stl
32.5 x 6.50 x 33.1

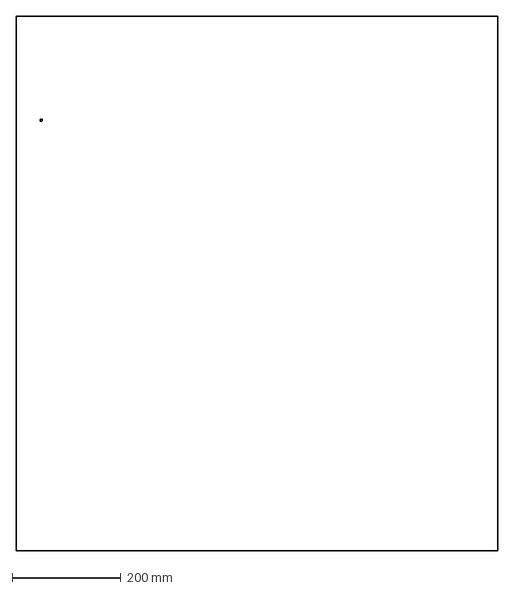
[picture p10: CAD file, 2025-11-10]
hardware/dxf/0031_Plotter_Base.dxf
886.0 x 982.5 mm

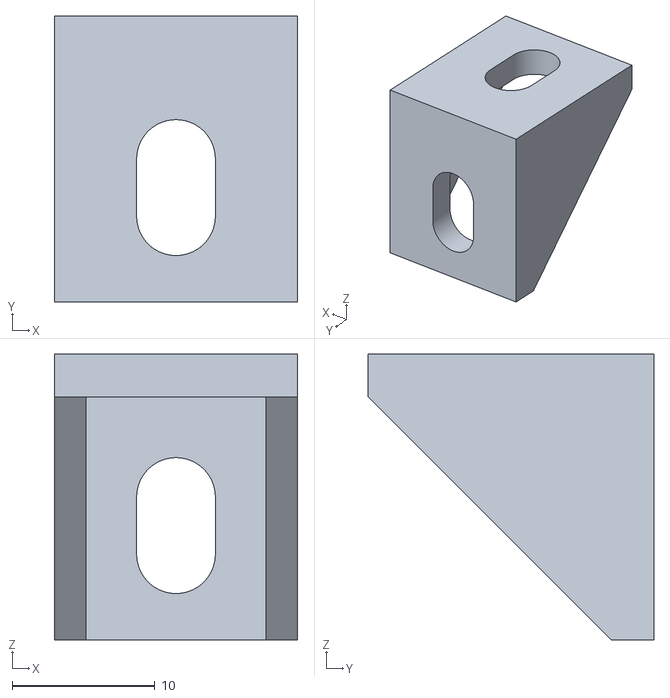
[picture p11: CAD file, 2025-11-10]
hardware/stl/0025_LBracket.stl
17.0 x 20.0 x 20.0

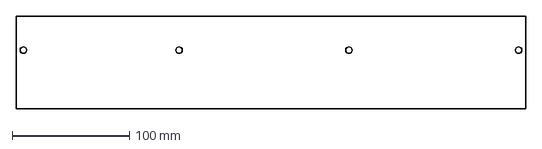
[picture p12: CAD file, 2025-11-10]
hardware/dxf/0032_ControlPanelBackPlate.dxf
435.0 x 79.0 mm

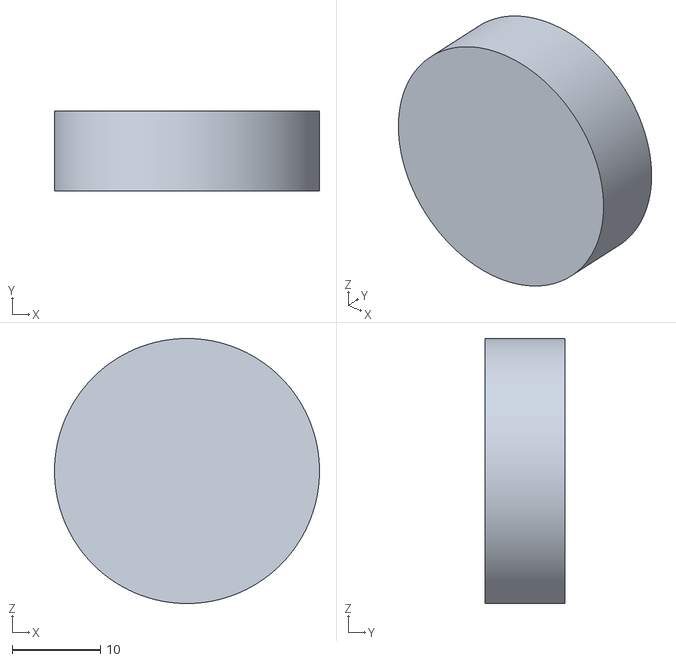
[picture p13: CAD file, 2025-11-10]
hardware/stl/0031_ToolLoadPuck_9mm.stl
30.0 x 9.00 x 30.0

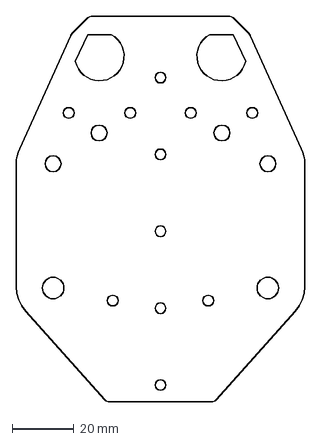
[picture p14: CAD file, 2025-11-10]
hardware/dxf/004_ZAxisSupportPlate_Sketch.dxf
93.8 x 125.5 mm

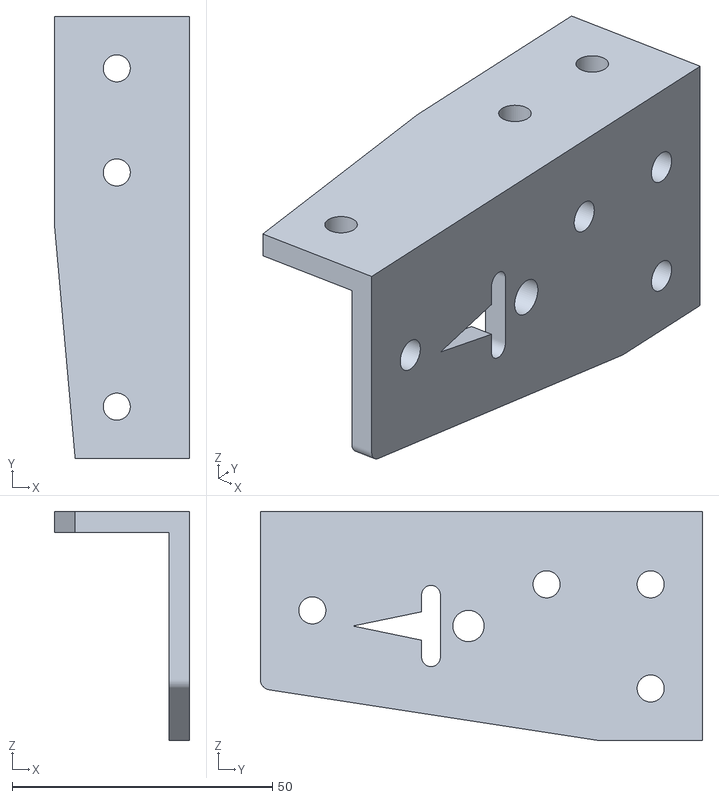
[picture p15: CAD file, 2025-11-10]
hardware/stl/0016_LeftFoot.stl
26.0 x 85.0 x 44.0

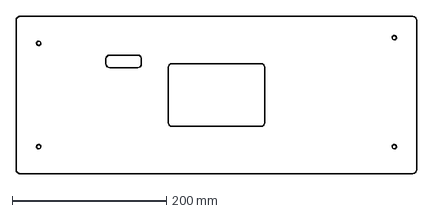
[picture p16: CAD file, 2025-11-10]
hardware/dxf/0030_ControlPanelBoard_Sketch.dxf
520.0 x 204.0 mm

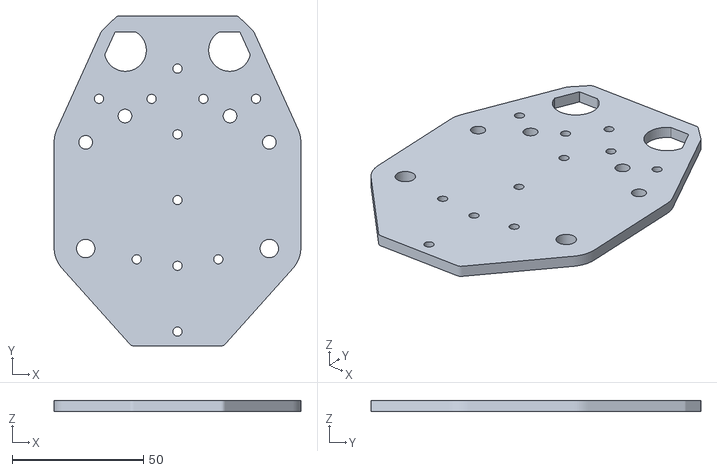
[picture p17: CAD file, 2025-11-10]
hardware/stl/0004_ZAxisSupportPlate.stl
93.8 x 125.5 x 4.00

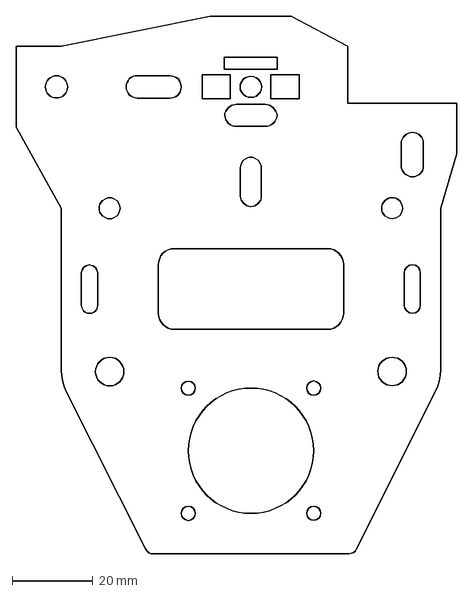
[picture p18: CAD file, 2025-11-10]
hardware/dxf/0010_YGantryBackPlate_Sketch.dxf
109.0 x 133.0 mm

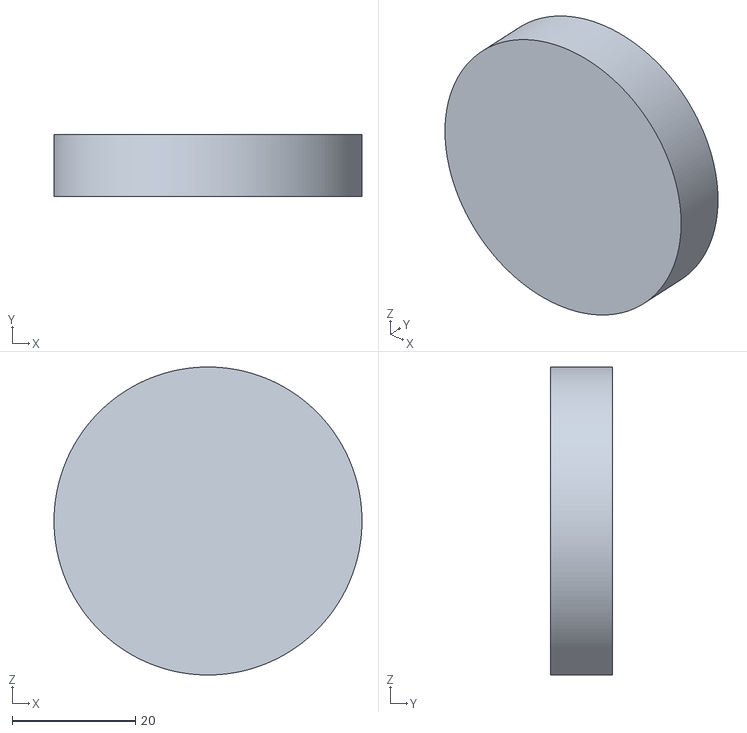
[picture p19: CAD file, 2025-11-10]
hardware/stl/0030_ToolLoadPuck_10mm.stl
50.0 x 10.0 x 50.0

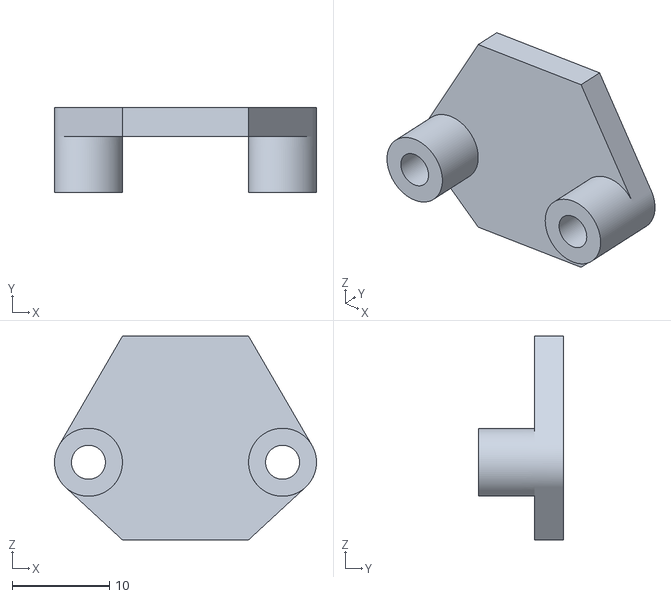
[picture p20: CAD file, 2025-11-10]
hardware/stl/0014_TopLimitSwitchBracketZ.stl
27.0 x 8.80 x 21.0

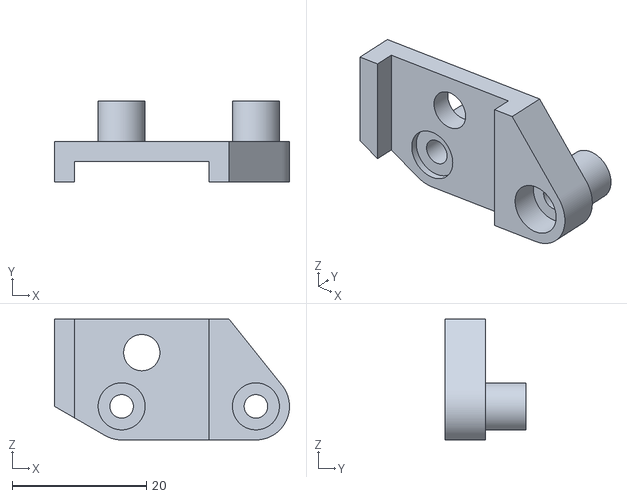
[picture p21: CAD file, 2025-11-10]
hardware/stl/0013_BottomLimitSwitchBracket.stl
35.0 x 12.0 x 18.0

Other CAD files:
hardware/stl/0037_SpringPenBracket.stl
hardware/stl/0022_PowerSupplyBracket.stl
hardware/stl/0005_CarriageBracket.stl
hardware/stl/0002_PenHolderBracket.stl
hardware/dxf/0012_YGantryWheelHolder.dxf
hardware/stl/0001_PenHolderBackPlate.stl
hardware/stl/0003_PenRailSupport.stl
hardware/stl/0006_ZNEMATopSupport.stl
hardware/stl/0007_ZBottomSupport.stl
hardware/stl/0008_XAxisBackPlate.stl
hardware/stl/0009_XAxisRailSupport.stl
hardware/stl/0010_YGantryBackPlate.stl
hardware/stl/0011_YGantryRailBracket.stl
hardware/stl/0012_YGantryWheelHolder.stl
hardware/stl/0014_TopLimitSwitchBracket.stl
hardware/stl/0015_LimitSwitchZColumn6mm.stl
hardware/stl/0017_RightFoot.stl
hardware/stl/0018_AC-01APowerBracket.stl
hardware/stl/0020_ScreenBracket.stl
hardware/stl/0021_FrontCoverPanel.stl
hardware/stl/0023_M5PLeftBracket.stl
hardware/stl/0024_M5PRightBracket.stl
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

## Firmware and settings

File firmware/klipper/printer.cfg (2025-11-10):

[include mainsail.cfg]
[include aria_macros_simple.cfg]
[include aria_macros_screen_simple.cfg]

# Aria Art Plotter - Klipper Configuration
# Copyright (c) 2025 Gustavo Mayoral
#
# This file is part of the Aria Art Plotter project.
# 
# Hardware License: CERN Open Hardware Licence Version 2 - Strongly Reciprocal (CERN-OHL-S-2.0)
# Documentation License: Creative Commons Attribution-ShareAlike 4.0 International (CC BY-SA 4.0)
# Software License: GNU General Public License v3.0 (GPL-3.0)
#
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
# Project: https://github.com/gustavomayoral/aria_art_plot
# Support: https://ko-fi.com/ariaartplot
# Web: https://aria-art.com

# ####################################################################################################
# IMPORTANT:

# MCU Configuration
[mcu]
serial: /dev/serial/by-id/usb-Klipper_stm32g0b1xx_1B00530011504D5930363820-if00  # Serial ID for BIGTREETECH Manta M5P

# OLED Display configuration
[oled_display]
serial_port: /dev/serial/by-id/usb-Seeed_Seeed_XIAO_M0_E85C0F8B503058414E2E3120FF0F0916-if00
baud_rate: 115200
timeout: 1.0

[respond]
default_type : echo

# ####################################################################################################

[mcu cb1]
serial: /tmp/klipper_host_mcu

[pause_resume]

[display_status]

# X-axis configuration (500mm travel)
[stepper_x]
step_pin: PC8
dir_pin: PC9
enable_pin: !PA15
microsteps: 16
rotation_distance: 40  # for GT2 belt with 20 tooth pulley (2mm pitch * 20 teeth)
endstop_pin: ^PD3      # X-min endstop (adjust if needed)
position_endstop: 0
position_max: 524
homing_speed: 150
homing_retract_dist: 5
homing_positive_dir: false

# Y-axis configuration (500mm travel)
[stepper_y]
step_pin: PA10
dir_pin: PA14
enable_pin: !PA13
microsteps: 16
rotation_distance: 40  # for GT2 belt with 20 tooth pulley
endstop_pin: ^PD2      # Y-min endstop (adjust if needed)
position_endstop: 0
position_max: 510
homing_speed: 150
homing_retract_dist: 5
homing_positive_dir: false

# Second Y motor (connected to duplicate the first Y)
[stepper_y1]
step_pin: PB0
dir_pin: !PB1
enable_pin: !PC4
microsteps: 16
rotation_distance: 40

# Z-axis configuration (35mm travel)
[stepper_z]
step_pin: PB12
dir_pin: !PB11
enable_pin: !PA8
microsteps: 16
rotation_distance: 8   # For a standard lead screw
endstop_pin: ^PC3      # Z-min endstop (adjust if needed)
#endstop_pin: probe:z_virtual_endstop
position_endstop: 38
position_max: 40
position_min:-10
homing_speed: 20
homing_retract_dist: 3
homing_positive_dir: true

# TMC2209 UART configuration for X (M1)
[tmc2209 stepper_x]
uart_pin: PD9
uart_address: 0
run_current: 0.8
stealthchop_threshold: 999999

# TMC2209 UART configuration for Y (M2)
[tmc2209 stepper_y]
uart_pin: PD8
uart_address: 0
run_current: 0.8
stealthchop_threshold: 999999

# TMC2209 UART configuration for Y1 (M5)
[tmc2209 stepper_y1]
uart_pin: PA6
uart_address: 0
run_current: 0.8
stealthchop_threshold: 999999

# TMC2209 UART configuration for Z (M4)
[tmc2209 stepper_z]
uart_pin: PB2
uart_address: 0
run_current: 0.8
stealthchop_threshold: 999999

# Board pin definitions for display
[board_pins]
aliases:
    # EXP1 header
    EXP1_1=PD5, EXP1_3=PB3, EXP1_5=PB5, EXP1_7=PB7, EXP1_9=<GND>,
    EXP1_2=PD4, EXP1_4=PD6, EXP1_6=PB4, EXP1_8=PB6, EXP1_10=<5V>,
    # EXP2 header
    EXP2_1=PB14, EXP2_3=PB8, EXP2_5=PC10, EXP2_7=PC12, EXP2_9=<GND>,
    EXP2_2=PB13, EXP2_4=PB9, EXP2_6=PB15, EXP2_8=<RST>, EXP2_10=<NC>

# Display configuration
[display]
lcd_type: uc1701
cs_pin: EXP1_3
a0_pin: EXP1_4
rst_pin: EXP1_5
contrast: 63
encoder_pins: ^EXP2_5, ^EXP2_3
click_pin: ^!EXP1_2
spi_software_miso_pin: EXP2_1
spi_software_mosi_pin: EXP2_6
spi_software_sclk_pin: EXP2_2

[neopixel btt_mini12864]
pin: EXP1_6
chain_count: 3
# Bright white on power-up to show system is starting
initial_RED: 1.0
initial_GREEN: 1.0
initial_BLUE: 1.0
color_order: RGB

# Change colors after boot to indicate Klipper is ready
[delayed_gcode setdisplayneopixel]
initial_duration: 1
gcode:
    # Amber/orange color to indicate ready state
    SET_LED LED=btt_mini12864 RED=1 GREEN=0.2 BLUE=0 INDEX=1 TRANSMIT=0
    SET_LED LED=btt_mini12864 RED=1 GREEN=0.2 BLUE=0 INDEX=2 TRANSMIT=0
    SET_LED LED=btt_mini12864 RED=1 GREEN=0.2 BLUE=0 INDEX=3
    RESPOND TYPE=command MSG="Display initialized - Aria Plotter Ready"

# Printer Kinematics and Motion Settings
[printer]
kinematics: cartesian
max_velocity: 400
max_accel: 1500
max_z_velocity: 80
max_z_accel: 500
square_corner_velocity: 3.0

# Optional wrapper macros with different names (if you want them)
[gcode_macro SEND_OLED]
description: Send message to OLED display (wrapper)
gcode:
    {% set MSG = params.MSG|default("Hello World")|string %}
    OLED_MESSAGE MSG="{MSG}"

[gcode_macro CLEAR_OLED] 
description: Clear OLED display (wrapper)
gcode:
    OLED_CLEAR

[gcode_macro CANCEL_PRINT]
rename_existing: CANCEL_PRINT_BASE
description: Cancel the actual running print
gcode:
    {% if printer.print_stats.state == "printing" or printer.print_stats.state == "paused" %}
        CANCEL_PRINT_BASE
    {% endif %}
                               
    G28 Z                                
    #G1 X262 Y255 F12000               # Move to center position safely
    G1 X0 Y0 F12000
    M84                              # Disable steppers
    M117 Print Cancelled
    OLED_MESSAGE MSG="Print\nCancelled"

[gcode_macro PAUSE]
rename_existing: PAUSE_BASE
description: Pause the actual running print
gcode:
    {% if printer.print_stats.state == "printing" %}
        PAUSE_BASE
        G28 Z                          # Lift pen when pausing
        G1 X262 Y255 F12000              # Move to safe position
        M117 Print Paused
        OLED_MESSAGE MSG="Print\nPaused"
    {% else %}
        RESPOND TYPE=error MSG="No print to pause"
    {% endif %}

# Improve virtual_sdcard error handling
[virtual_sdcard]
path: /home/biqu/printer_data/gcodes  
on_error_gcode:
    RESPOND TYPE=error MSG="SD card error occurred"
    OLED_MESSAGE MSG="SD Card\nError!"
    CANCEL_PRINT

#*# <---------------------- SAVE_CONFIG ---------------------->
#*# DO NOT EDIT THIS BLOCK OR BELOW. The contents are auto-generated.
#*#
#*# [bed_mesh canvas_pressure]
#*# version = 1
#*# points =
#*# 	0.000000, -0.218750, -0.437500, -0.609375, -0.750000, -0.609375, -0.437500, -0.218750, 0.000000
#*# 	-0.218750, -0.437500, -0.656250, -0.828125, -0.968750, -0.828125, -0.656250, -0.437500, -0.218750
#*# 	-0.437500, -0.656250, -0.875000, -1.046875, -1.187500, -1.046875, -0.875000, -0.656250, -0.437500
#*# 	-0.609375, -0.828125, -1.046875, -1.218750, -1.359375, -1.218750, -1.046875, -0.828125, -0.609375
#*# 	-0.750000, -0.968750, -1.187500, -1.359375, -2.000000, -1.359375, -1.187500, -0.968750, -0.750000
#*# 	-0.609375, -0.828125, -1.046875, -1.218750, -1.359375, -1.218750, -1.046875, -0.828125, -0.609375
#*# 	-0.437500, -0.656250, -0.875000, -1.046875, -1.187500, -1.046875, -0.875000, -0.656250, -0.437500
#*# 	-0.218750, -0.437500, -0.656250, -0.828125, -0.968750, -0.828125, -0.656250, -0.437500, -0.218750
#*# 	0.000000, -0.218750, -0.437500, -0.609375, -0.750000, -0.609375, -0.437500, -0.218750, 0.000000
#*# x_count = 9
#*# y_count = 9
#*# mesh_x_pps = 2
#*# mesh_y_pps = 2
#*# algo = bicubic
#*# tension = 0.2
#*# min_x = 44.0
#*# max_x = 480.0
#*# min_y = 6.0
#*# max_y = 506.0
#*#
#*# [bed_mesh bed_surface]
#*# version = 1
#*# points =
#*# 	  0.357500, 0.102500, -0.020000, -0.107500, -0.140000, -0.142500, -0.137500, -0.092500, -0.007500
#*# 	  0.880000, 0.675000, 0.570000, 0.495000, 0.535000, 0.540000, 0.577500, 0.622500, 0.720000
#*# 	  1.082500, 0.677500, 0.792500, 0.685000, 0.660000, 0.680000, 0.695000, 0.807500, 0.935000
#*# 	  1.262500, 1.137500, 1.070000, 1.010000, 0.985000, 1.010000, 1.065000, 1.135000, 1.195000
#*# 	  1.315000, 1.240000, 1.207500, 1.140000, 1.200000, 1.145000, 1.180000, 1.252500, 1.330000
#*# 	  1.350000, 1.327500, 1.382500, 1.467500, 1.435000, 1.420000, 1.415000, 1.462500, 1.477500
#*# 	  1.332500, 1.360000, 1.455000, 1.495000, 1.410000, 1.420000, 1.455000, 1.430000, 1.467500
#*# 	  1.320000, 1.295000, 1.372500, 1.515000, 1.522500, 1.510000, 1.517500, 1.507500, 1.515000
#*# 	  0.795000, 0.897500, 1.002500, 1.042500, 1.125000, 1.142500, 1.152500, 1.130000, 1.195000
#*# x_count = 9
#*# y_count = 9
#*# mesh_x_pps = 2
#*# mesh_y_pps = 2
#*# algo = bicubic
#*# tension = 0.2
#*# min_x = 44.0
#*# max_x = 480.0
#*# min_y = 6.0
#*# max_y = 506.0

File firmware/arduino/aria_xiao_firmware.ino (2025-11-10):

/*
 * Aria Art Plotter - XIAO-OLED DRIVER
 * 
 * Copyright (c) 2025 Gustavo Mayoral
 * 
 * This file is part of the Aria Art Plotter project.
 * 
 * Hardware License: CERN-OHL-S-2.0
 * Documentation License: CC BY-SA 4.0
 * Software License: GPL-3.0
 * 
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
 * Project: https://github.com/gustavomayoral/aria_art_plot
 * Support: https://ko-fi.com/ariaartplot
 * Web: https://aria-art.com
 */

#include <Wire.h>
#include <Adafruit_GFX.h>
#include <Adafruit_SSD1306.h>

#define SCREEN_WIDTH 128
#define SCREEN_HEIGHT 32
#define OLED_RESET -1
#define SCREEN_ADDRESS 0x3C

#define MAX_MESSAGE_LENGTH 128       // Max chars for messages to fit RAM
#define MAX_CHARS_PER_LINE 21        // For text wrapping on OLED
#define Y_POS_INCREMENT 8            // Line height in pixels
#define STARTUP_TIMEOUT_MS 50000     // 50 seconds for loading
#define PROGRESS_BAR_WIDTH 100       // Progress bar dimensions
#define PROGRESS_BAR_HEIGHT 6
#define PROGRESS_BAR_X 14
#define PROGRESS_BAR_Y 20
#define PROGRESS_UPDATE_MS 500       // Min update interval for animation
#define LOOP_DELAY_MS 100            // Non-blocking loop interval

Adafruit_SSD1306 display(SCREEN_WIDTH, SCREEN_HEIGHT, &Wire, OLED_RESET);

char currentMessage[MAX_MESSAGE_LENGTH] = "ARIA Starting.\nPlease wait...";
char incomingMessage[MAX_MESSAGE_LENGTH];
bool messageComplete = false;
unsigned long lastUpdate = 0;
unsigned long startupTime = 0;
int loadingPercent = 0;
bool klipperConnected = false;
bool showingFallback = false;

// Updates the OLED display with the current message, handling multi-line text.
void updateDisplay() {
  display.clearDisplay();  // Clear only when needed; could optimize further
  display.setTextSize(1);
  display.setTextColor(SSD1306_WHITE);
  display.setCursor(0, 0);
  
  renderMultiLineText(currentMessage);
  
  display.display();
}

// Renders multi-line text with wrapping (split from updateDisplay for clarity).
void renderMultiLineText(const char* text) {
  int yPos = 0;
  const char* lineStart = text;
  
  while (*lineStart && yPos < SCREEN_HEIGHT - Y_POS_INCREMENT) {
    char line[MAX_CHARS_PER_LINE + 1];
    int charCount = 0;
    
    // Extract line up to newline or max chars
    while (*lineStart && *lineStart != '\n' && charCount < MAX_CHARS_PER_LINE) {
      line[charCount++] = *lineStart++;
    }
    line[charCount] = '\0';  // Null-terminate
    
    display.setCursor(0, yPos);
    display.println(line);
    yPos += Y_POS_INCREMENT;
    
    if (*lineStart == '\n') lineStart++;  // Skip newline
  }
}

void setup() {
  Serial.begin(115200);  // USB CDC on XIAO
  
  Wire.begin();  // I2C init
  
  // Initialize OLED with retries for stability
  int retries = 3;
  while (retries > 0 && !display.begin(SSD1306_SWITCHCAPVCC, SCREEN_ADDRESS)) {
    Serial.println("SSD1306 allocation failed, retrying...");
    delay(1000);
    retries--;
  }
  if (retries == 0) {
    Serial.println("SSD1306 failed to initialize");
    for (;;);  // Halt if critical failure
  }
  
  display.clearDisplay();
  display.setTextSize(1);
  display.setTextColor(SSD1306_WHITE);
  display.setCursor(0, 0);
  display.println("ARIA Starting");
  display.println("Loading:");
  display.display();
  
  startupTime = millis();
  Serial.println("OLED_READY");
}

void loop() {
  static unsigned long lastLoop = 0;
  
  if (millis() - lastLoop >= LOOP_DELAY_MS) {
    handleSerial();
    
    if (!klipperConnected && !showingFallback) {
      showLoadingAnimation();
    }
    
    lastLoop = millis();
  }
}

// Handles serial input with fixed buffer to prevent overflow.
void handleSerial() {
  static int msgIndex = 0;
  
  while (Serial.available()) {
    char receivedChar = Serial.read();
    
    if (receivedChar == '\n') {
      incomingMessage[msgIndex] = '\0';  // Null-terminate
      messageComplete = true;
      break;
    } else if (msgIndex < MAX_MESSAGE_LENGTH - 1) {
      incomingMessage[msgIndex++] = receivedChar;
    } else {
      Serial.println("ERROR: Message too long");
      msgIndex = 0;
      return;
    }
  }
  
  if (messageComplete) {
    processCommand(incomingMessage);
    msgIndex = 0;
    incomingMessage[0] = '\0';
    messageComplete = false;
  }
}

void processCommand(const char* command) {
  // Skip leading whitespace (simple trim)
  while (*command == ' ' || *command == '\t') command++;
  
  if (strncmp(command, "MSG:", 4) == 0) {
    command += 4;  // Skip "MSG:"
    strncpy(currentMessage, command, MAX_MESSAGE_LENGTH - 1);
    currentMessage[MAX_MESSAGE_LENGTH - 1] = '\0';
    
    // Replace "\\n" with "\n" manually
    char* pos;
    while ((pos = strstr(currentMessage, "\\n")) != NULL) {
      *pos = '\n';
      memmove(pos + 1, pos + 2, strlen(pos + 2) + 1);
    }
    
    klipperConnected = true;
    showingFallback = false;
    updateDisplay();
    Serial.println("OK");
  } else if (strcmp(command, "CLEAR") == 0) {
    display.clearDisplay();
    display.display();
    currentMessage[0] = '\0';
    Serial.println("OK");
  } else if (strcmp(command, "STATUS") == 0) {
    Serial.println("READY");
  } else {
    Serial.println("UNKNOWN_COMMAND");
  }
}

void showLoadingAnimation() {
  unsigned long elapsed = millis() - startupTime;
  int newPercent = (elapsed * 100UL) / STARTUP_TIMEOUT_MS;  // Use UL to avoid overflow
  
  if (newPercent > 100) {
    if (!showingFallback) {
      showingFallback = true;
      display.clearDisplay();
      display.setTextSize(1);
      display.setTextColor(SSD1306_WHITE);
      display.setCursor(0, Y_POS_INCREMENT);
      display.println("ARIA ART ROBOT");
      display.display();
    }
    return;
  }
  
  // Update only if percent changed or timeout
  if (newPercent != loadingPercent || (millis() - lastUpdate) > PROGRESS_UPDATE_MS) {
    loadingPercent = newPercent;
    lastUpdate = millis();
    
    display.clearDisplay();
    display.setTextSize(1);
    display.setTextColor(SSD1306_WHITE);
    display.setCursor(0, 0);
    display.println("ARIA 1.0 Starting");
    display.print("Loading: ");
    
    // Draw progress bar
    display.drawRect(PROGRESS_BAR_X, PROGRESS_BAR_Y, PROGRESS_BAR_WIDTH, PROGRESS_BAR_HEIGHT, SSD1306_WHITE);
    
    int fillWidth = (loadingPercent * (PROGRESS_BAR_WIDTH - 2)) / 100;
    if (fillWidth > 0) {
      display.fillRect(PROGRESS_BAR_X + 1, PROGRESS_BAR_Y + 1, fillWidth, PROGRESS_BAR_HEIGHT - 2, SSD1306_WHITE);
    }
    
    display.display();
  }
}

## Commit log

2025-11-10 Initial release: Aria Art Plotter v1.0
    [0001_PenHolderBackPlate.stl, 0002_PenHolderBracket.stl, 0003_PenRailSupport.stl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]
2026-02-26 MGN9 updated to MGN12 in BOM and assembly docs
    Updated docs to change MGN9 to MGN12 for linear rails. Updated amazon links to align with change.
    [BOM.csv]

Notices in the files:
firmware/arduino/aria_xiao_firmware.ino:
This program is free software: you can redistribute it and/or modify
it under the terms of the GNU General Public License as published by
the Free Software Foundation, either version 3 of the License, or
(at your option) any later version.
